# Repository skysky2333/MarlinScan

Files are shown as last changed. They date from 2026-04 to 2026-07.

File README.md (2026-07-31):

# MarlinScan

MarlinScan is a local scanning workstation that uses a Marlin-controlled printer as a motion stage and a USB-tethered Nikon 1 J4 as the image source. It captures overlapping high-resolution tiles from flat or nearly flat subjects and builds a color-consistent mosaic.

The primary application is a Python service with a browser interface. Printer and camera access remain in the local Python process; the browser handles positioning, calibration, scan setup, progress, stopping, and result review.

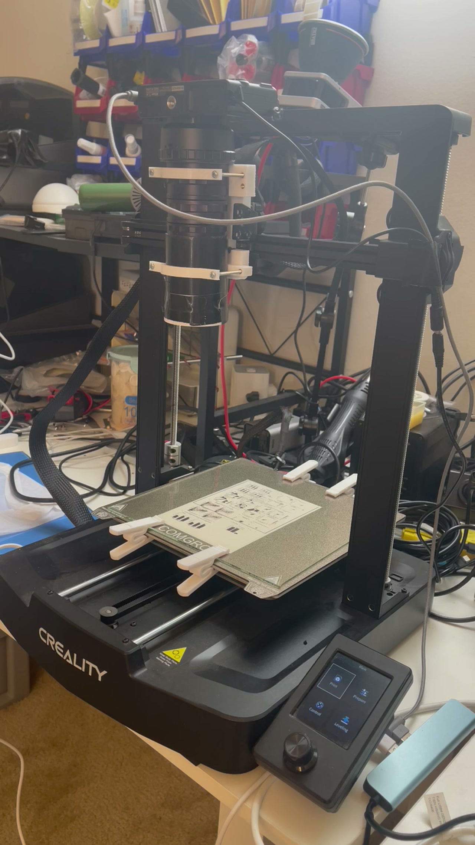
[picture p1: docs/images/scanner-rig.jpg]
MarlinScan hardware scanning a test target


One measured 140-position scan produced a `38,324 x 36,167` image: **1.386 gigapixels at 4,998 DPI**. By output pixel count, that is about 23 times a [61 MP Sony A7R V frame](https://www.sony.com/electronics/support/e-mount-body-ilce-7-series/ilce-7rm5/specifications), 9.2 times a [151 MP Phase One IQ4 frame](https://www.phaseone.com/wp-content/uploads/2021/12/IQ_Camera_System_Overview_Flyer.pdf), and 5.8 times the A7R V's 240.8 MP Pixel Shift output. This is a spatial-output comparison, not a claim of single-shot equivalence: the MarlinScan result required a static flat subject, 140 Nikon captures, stitching, about 53 minutes, and a 67 GB working project. Dynamic range, noise, color accuracy, optical resolution, and motion tolerance still depend on each tile and the physical setup.

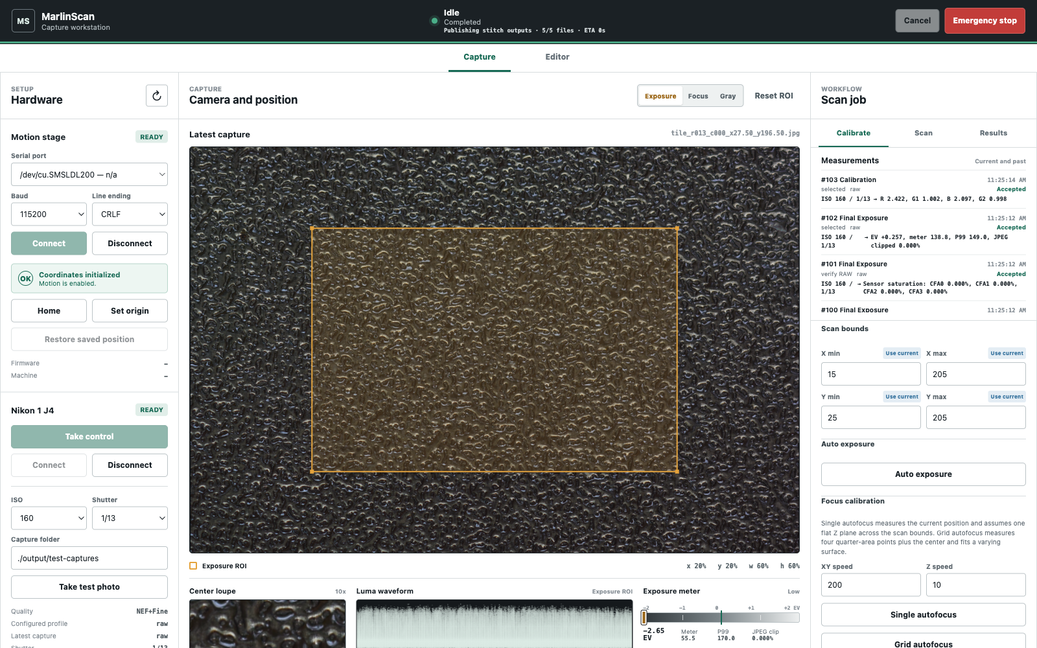
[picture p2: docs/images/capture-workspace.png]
MarlinScan Capture workspace


Start with the [documentation index](docs/index.md), [five-minute workflow](docs/quick-start.md), or [complete configuration reference](docs/configuration.md). The focused guides cover [hardware](docs/hardware.md), [macOS installation](docs/install-macos.md), [Capture](docs/capture-workspace.md), [Editor](docs/editor.md), [outputs and large-image tools](docs/outputs.md), [recovery](docs/troubleshooting.md), [architecture](docs/architecture.md), and the [measured benchmark](docs/benchmarks.md).

## Hardware Scope

- A Marlin-compatible printer or motion stage connected over USB serial
- A Nikon 1 J4 connected directly over Micro-USB and controlled through libgphoto2
- A manual lens and fixed illumination
- A neutral gray reference for white-balance calibration

The primary workflow is USB-only. Nikon Wi-Fi is not used. The J4 does not provide live view over its libgphoto2 USB driver, so the browser displays the latest captured JPEG rather than a video stream.

Set aperture and the lens focus ring physically before calibration. MarlinScan never controls either. Its focus calibration changes the camera-to-subject distance with the printer Z axis.

## Safety And Recovery

- Clear the full configured XYZ travel before connecting or moving the printer.
- Keep the camera mount, lens, nozzle, subject, and cables clear throughout homing, jogging, calibration, and scanning.
- Watch the machine while it moves and keep the emergency-stop control accessible.
- Every new printer connection starts with coordinates uninitialized. Run Home (`G28`), deliberately set the current position as the origin (`G92`), or restore a saved position before motion is enabled.
- MarlinScan remembers the last confirmed XYZ position for each serial port. **Restore saved position** sends that position back with `G92`; it does not move or measure the stage. Use it only when the printer has not physically moved since the position was recorded. Home instead if power loss, released motors, manual handling, or any other event may have changed the position.
- Cancel ends normal work cooperatively after the active command finishes and keeps the printer session and initialized coordinates. Use Emergency Stop when motion must be interrupted immediately.
- Emergency Stop sends `M112` and faults the printer session. Reset or power-cycle the printer if its firmware requires it, disconnect and reconnect it in MarlinScan, then initialize coordinates again.
- MarlinScan cannot change the speed of a `G28` homing cycle. Homing speed is set in the printer's Marlin firmware configuration; the browser speed controls apply to commanded moves and jogging only.

Partial captures already written to disk remain available after a stopped or failed scan. Do not treat an incomplete output folder as a completed mosaic.

## Install On macOS

Python `3.10+` is recommended. Install the gphoto2 CLI and its libgphoto2 dependency, plus native libvips and OpenEXR support:

```bash
brew install gphoto2 vips openexr
```

Install the Python dependencies into the `3dprinter` Conda environment from the repository root:

```bash
conda activate 3dprinter
python -m pip install -r requirements.txt
```

The requirements include the Python gphoto2 binding, FastAPI service, RAW developer, image analysis, serial control, and stitching dependencies.

## Launch

From the repository root:

```bash
conda activate 3dprinter
python -m v3se_printer
```

This starts the service on `http://127.0.0.1:8000/` and opens the default browser. It binds only to this Mac. To suppress browser opening or select another local port:

```bash
python -m v3se_printer --no-open
python -m v3se_printer --port 8010
```

The browser defaults test captures, calibration runs, and scans to `./output/` beneath the directory where MarlinScan was launched. You can replace any of those paths before starting an operation.

Without activating Conda first:

```bash
conda run -n 3dprinter python -m v3se_printer
```

## Nikon USB Session

1. Turn on the Nikon J4 and connect it directly to the Mac with a data-capable Micro-USB cable.
2. Close macOS Photos, Image Capture, and any other camera client.
3. In the Nikon panel, select **Take control**. On macOS this terminates `ptpcamerad`, which otherwise owns the camera interface.
4. Select **Connect**. MarlinScan then keeps one persistent gphoto session for capture and configuration.
5. Select the global ISO and shutter from the values reported by the camera, then take a test capture before moving into calibration. Connection sets the initial shutter to `1/6`.

Taking control can interrupt other macOS photo-import applications. Disconnect the Nikon in MarlinScan before using those applications again.

## Positioning And Capture Feedback

Manual moves default to `200 mm/s` on XY and `10 mm/s` on Z. Hold-to-jog defaults to `100 mm/s` on XY and `10 mm/s` on Z. Calibration and scan motion also default to `200 mm/s` on XY and `10 mm/s` on Z. Adjust these values for the mechanics and payload of the specific stage.

Home first runs the printer's normal `G28`, then raises to `Z203` and moves to the bed center at `X110 Y110`. Confirm that this entire path is clear before starting it.

When the Nikon is connected, MarlinScan automatically captures a **Small / JPEG Basic** still after Home, Restore saved position, each completed manual move, and the end of each jog. These preview captures keep the displayed frame current while minimizing transfer time; they are not scan-quality files. The camera's prior capture settings are restored after each preview.

The latest JPEG view includes three draggable regions for exposure, focus, and the gray reference. The inspection tools show a luma waveform, a robust midtone meter, P99 and JPEG-clipping diagnostics for the exposure region, and a `10x` center loupe for checking detail. These are still-image tools because the J4 USB driver does not provide live view.

## Calibration And Scan

1. Connect the printer, then home it, deliberately set the current position as the origin, or safely restore its remembered position.
2. Connect the Nikon and select the global ISO and shutter used by every capture action.
3. Define the rectangular coverage of the finished image and select separate exposure, focus, and gray-card image regions.
4. Use **Single autofocus** at the current position for a flat subject, or **Grid autofocus** when focus height varies across the coverage.
5. Calibrate exposure, autofocus, and gray-card white balance as separate actions, or use **Run all calibration** to perform the combined workflow. Single autofocus applies its measured Z across the coverage; Grid autofocus measures the four quarter-area centers plus the exact center and fits a focus surface from all five peaks.
6. Confirm the measured camera footprint, which defaults to `25 x 17 mm`, and the desired overlap.
7. Start the scan after exposure, a valid flat or grid focus surface, and white balance are all calibrated. Until then, scanning remains disabled.

The ISO and shutter controls in the Nikon panel are the single source of truth for test captures, calibration, and scans. A scan snapshots their live camera values into `scan_params.json`. Auto exposure changes only the global shutter. It first meters a 2-98 percent winsorized JPEG luminance mean toward `128` as a fast coarse seed, then measures the matching NEF and lengthens an underfilled exposure toward 85 percent P99 in the brightest CFA channel. JPEG clipping, RAW P99, RAW saturation, and black pixels remain diagnostics rather than pass/fail requirements because high-contrast scenes cannot always retain both endpoints. If at least one percent of a RAW channel reaches 99.5 percent of sensor white, MarlinScan shortens the shutter by exactly one available step, verifies again, then accepts the best result with a warning if saturation remains. It never changes ISO or selects a shutter longer than one second.

Each focus-grid point probes `1 mm` below and above its starting Z. A clear improvement extends in that direction; an ambiguous response expands in both directions. The fine pass samples at `0.25 mm` and extends past an edge maximum until the global peak is bracketed. Peak confidence is measured against the complete sweep endpoints, so a broad peak or two-point plateau is valid while a genuinely flat curve fails. There is no user-defined focus range; the configured machine Z limits are the safety boundaries. Single autofocus captures a final analysis frame at the selected peak so the displayed image matches the stage position. The browser logs every focus score and each expansion, bracket, prominence, and selection decision.

Grid autofocus samples the four points formed by the 25 and 75 percent positions across the finished-image coverage area's width and height, plus the exact center. One bilinear surface is fitted from all five measured peaks and used only inside the declared coverage. Single autofocus creates a constant-Z surface from its measured point. After either autofocus mode or Run all calibration, bed clicks, absolute XY moves, XY jogging, and scan tiles automatically use the active surface Z. Z-only moves remain available for deliberate adjustment.

Scan bounds describe the finished image's physical coverage, not the camera-center travel. Defaults are `X15-205 mm` and `Y25-205 mm`; each scan minimum or maximum has a **Use current** button for the corresponding live stage coordinate. The outer tile centers are inset from those bounds by half the `25 x 17 mm` camera footprint, so the outer image edges meet the requested coverage. Tile spacing follows the selected overlap.

Each tile waits `1000 ms` after the final XYZ move before capture by default so stage vibration can decay. The Settle control applies to both normal and Quick acquisition and remains adjustable from `0` to `5000 ms`.

The Position map previews the separated tile grid from the current scan settings before capture. While scanning it shows the serpentine planned route, completed route, current location, completed count, active phase, and estimated phase time remaining. Status refreshes more frequently while work is active, and successful calibration or scanning opens Results automatically without an acknowledgement step.

Normal acquisition downloads each JPEG first so it can appear promptly, then its matching NEF, while RAW development overlaps the following tile. Optional **Quick acquisition** stores every JPEG+NEF pair on the camera card during stage motion, records the remote-to-tile mapping, and imports all pairs before development and stitching. Quick acquisition shortens the moving phase but tile images do not appear until import; normal acquisition remains the default.

Quick acquisition deletes every JPEG+NEF pair owned by that job and restores the previous camera storage target after success, Stop, or failure. It never enumerates or deletes unrelated card files. A deletion or storage-restore failure remains visible as a failed job so camera-space leaks are not hidden.

White balance comes from the selected neutral gray-card region in one matching JPEG+NEF capture. The reference must retain usable, unsaturated samples in every CFA channel. That pair also establishes one global linear exposure multiplier and records the camera-to-Rec.2020 matrix. All three are reused for every tile; per-tile auto white balance and automatic brightness are not used. The recipe also pins the rawpy and LibRaw versions, and regeneration fails if the installed engine differs. RAW development leaves saturated highlights unreconstructed and performs the working-space conversion in float, so unclipped channels and signed out-of-gamut values remain in the scene-linear master instead of being forced to a 16-bit boundary.

The browser estimates the scan sampling density below Camera footprint from the latest Large analysis or RAW capture. It shows X, Y, and nominal DPI and retains that estimate when a Small preview is captured.

The Measurements panel keeps the current session's exposure readings, focus scores, selected peaks, and white-balance gains, including the capture profile used for each measurement.

## Image Roles And Outputs

Each captured tile has four matching files:

- `.nef`: untouched Nikon RAW archival source
- `.jpg`: fine JPEG used for exposure and focus analysis, alignment, and quick inspection
- `_scene_linear.tif`: internal float32 linear Rec.2020 working tile
- `.tif`: deterministic 16-bit sRGB development of the same linear tile for inspection

MarlinScan uses three named Nikon profiles: `preview` is Small / JPEG Basic, `analysis` is Large / JPEG Fine, and `raw` is Large / NEF+Fine. The J4 does not advertise a remotely configurable color-space setting, so profiles contain only camera-supported controls. The Nikon panel shows both the configured profile and the profile that produced the latest image.

A scan directory also contains `scan_params.json`, `raw_development.json`, the incrementally written local `captures.json` and developed `tiles.json` manifests, a losslessly compressed tiled float32 `mosaic_scene_linear.exr`, a flat 16-bit `mosaic_full.tif`, a tiled multi-resolution 16-bit `mosaic_pyramidal.ome.tif`, an 8-bit `mosaic_thumb_2000.jpg`, and exact alignment transforms in `stitch_meta.json`. JPEGs establish alignment once; the same geometry composites the linear tiles, and both display TIFFs are derived from that shared mosaic. The pyramidal OME-TIFF has the same full-resolution pixels and sRGB profile as the flat TIFF, plus reduced-resolution SubIFD levels and OME metadata for whole-slide viewers such as QuPath. Quick acquisition additionally writes `camera_captures.json` as each pair is stored on the camera.

The NEFs, manifests, calibration state, development recipe, and transforms are the canonical editable project. The OpenEXR mosaic is a demosaiced scene-linear derivative that preserves wide-gamut float values above display white for large-scale editing. The TIFF tiles and mosaics remain display-referred sRGB images: demosaicing, calibrated white balance, sRGB conversion, gamma, and channel clipping are baked into them. ISO is fixed when the sensor is exposed and cannot be changed afterward; retain the untouched NEFs when original sensor data or a different development recipe matters.

## Image Editor

The **Editor** workspace loads completed RAW scan projects independently of the capture controls. The full-image view loads the saved 2000-pixel mosaic once; the Local RAW view uses the clickable tile map to load one RAW-derived tile. Both remain in GPU memory, so sliders, the five-point curve, and the eight-band HSL mixer update continuously without a Preview button. Switching back to Full Image does not rebuild the mosaic.

Basic includes a drawn-region global white-balance picker. Film separates Positive/Slide, Color Negative, and B&W Negative development, including unexposed-base sampling, density inversion and range controls, and channel-response controls where applicable. These sampling rectangles set global recipe values; they are not retained local masks. The editor intentionally has no brushes, adjustment masks, selections, dodge, or burn tools.

Custom scan output locations are remembered by the service, so their completed projects remain available in Editor after a restart.

Interactive previews are fast display proxies. **Apply to all RAW** performs the authoritative full-precision operation: it develops every original NEF with the shared recipe, reuses the scan's saved alignment transforms, and writes a new immutable numbered revision beneath the scan folder. Its dedicated progress panel reports every NEF, compositing, EXR, TIFF, pyramid, preview, metadata, and cleanup phase with count and ETA. Each revision contains a linear Rec.2020 working EXR, flat and pyramidal 16-bit TIFFs, a JPEG preview, and the exact edit and revision metadata. Original NEFs and earlier revisions are never overwritten.

Gigapixel scans are normally edited through the full-image proxy or a local RAW tile, then rendered tile by tile and composed with the saved geometry. This is also how large aerial and whole-slide systems avoid loading a complete image into interactive memory. The full-resolution NEF-backed project and float EXR are the archival/editable path; DNG is not the canonical output because common RAW editors cannot reliably open BigDNG mosaics of this size.

## Legacy Desktop And UVC Tools

The earlier Tk desktop application remains available explicitly:

```bash
python -m v3se_printer.app
```

It retains the existing UVC preview, printer maintenance, temperature, tuning, EEPROM, mouse-follow, and older scan tools. Those UVC workflows are separate from the Nikon J4 web workflow and do not add USB live view to the J4.

The standalone UVC browser server is also separate:

```bash
python -m camera_server
```

Only one process can own most UVC cameras at a time. On macOS, grant the terminal or Python launcher camera permission when using UVC hardware.

## Helper Tools

Rebuild outputs from an existing compatible scan folder:

```bash
python tools/restitch_scan.py output/scans/scan_YYYYMMDD_HHMMSS
```

Benchmark realtime serial motion:

```bash
python tools/rt_bench.py --port /dev/cu.wchusbserial1120 --dx 0.5 --feed 6000 --count 80
```

## Repository Layout

- `v3se_printer/web/`: local browser service and interface
- `v3se_printer/service.py`: scan workflow orchestration
- `v3se_printer/nikon.py`: Nikon J4/libgphoto2 camera control
- `v3se_printer/printer.py`: bounded Marlin motion control
- `v3se_printer/calibration.py`: exposure and printer-Z focus calibration
- `v3se_printer/raw.py`: fixed-white-balance 16-bit RAW development
- `v3se_printer/scan/`: tile alignment, composition, and output writing
- `v3se_printer/app.py` and `v3se_printer/ui/`: legacy Tk/UVC application
- `camera_server/`: standalone legacy UVC browser server

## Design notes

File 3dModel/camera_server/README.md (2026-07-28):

# Camera server optical stand

These models support the standalone server launched with `python -m camera_server`. They are separate from the printer-controlled scan mount in `3dModel/printer_scan/`.

- `optical_stand.step`: a 54 mm tube clamp on a wide freestanding rear mount.
- `monolithic_stand_body.step`: an optional version that fuses the stand base, mast, and fixed clamp carrier into one solid.

Printable items 02-04 form the modular stand. Items 05-06 are the monolithic alternative.

The phrase "should be exceed 350 mm" is interpreted as "must not exceed 350 mm in any axis."

## Freestanding optical mount

The clamp is attached radially from behind through the gap between its lower and upper bands. No mast, beam, socket, or floor rail crosses the vertical 54 mm tube path above or below the clamps.

- Overall size: 300 x 288.959 x 288 mm
- Tube bore: 54 mm
- Clamp outside diameter: 62 mm
- Clamp screw axes: 72 mm apart
- Lower clamp: 8 mm high
- Upper clamp: 25 mm high
- Vertical spacing between clamp bases: 65 mm
- Floor rails: 24 mm wide x 16 mm high
- Head beam: 44 mm wide x 50 mm high

The floor base is one continuous print with no leg joints or leg holes. Each front rail first runs sideways to `X=+/-138`, then turns toward the user to `Y=-120`; the rounded rear rails spread to `X=+/-115`, `Y=145`. The forward rails have inner faces at `X=+/-126`, leaving a verified 246 x 155 mm clear floor area from `X=-123..123`, `Y=-105..50` beneath the tube.

The fixed clamp carrier, broad rear beam, mast contact pad, and socket are one solid. Part 4 now presses downward over the rectangular mast through a closed four-sided socket with a 6 mm rear wall, then seats against an integrated top stop. Its 50.6 x 30.6 mm cavity provides 0.30 mm broad-face clearance around the 50 x 30 mm mast. Four rounded side pads create 0.10 mm interference per side, while four front and four rear bearing pads keep the mast aligned without full-face rubbing. A 1 mm chamfer around the mast top provides a gradual lead-in. There is no separate rear bracket, thin center bridge, or head-joint M5 hardware.

## One-piece stand variant

`printable/05_monolithic_stand_body.stl` combines printable items 2, 3, and the fixed carrier from item 4 into one continuous solid. The mast socket is filled and fused through the base, the carrier is fused across the full mast contact face, and the three obsolete M5 assembly holes are removed.

The lower and upper clamp caps remain removable and are supplied together in `printable/06_monolithic_clamp_caps.stl`. They cannot be fused to the body because the 54 mm camera tube must enter through the open front of the clamps.

- Overall body size: 300 x 288.999 x 288 mm
- Body count: one closed solid
- Tube bore and clamp geometry: unchanged from the modular stand
- M5 stand hardware: not required
- Required printer space: 300 x 289 x 288 mm for the body alone, or about 320 x 310 mm with the recommended brim; a 350 x 350 x 350 mm printer is recommended

Print the body upright in its supplied orientation with a 10 mm brim. Use build-plate-only organic support under the fixed carrier, carefully blocked from the tube bore, screw holes, and insert pockets. Use 6-8 walls and 35-45% gyroid or cubic infill for PETG.

The one-piece version removes joints, but its upright mast is built across horizontal layer interfaces. The modular version's horizontally printed mast is directionally stronger and remains the preferred version for a heavy camera or frequent handling.

## Print files

STL does not contain a unit field; these files use millimeter coordinates. Import them as millimeters and keep the supplied orientations.

| File | Quantity | Bounding box | Supports |
| --- | ---: | --- | --- |
| `printable/02_stand_base.stl` | 1 | 300 x 288.999 x 74 mm | None; requires at least 310 x 300 mm usable area; a 350 mm bed leaves brim clearance |
| `printable/03_rear_mast.stl` | 1 | 50 x 250 x 30 mm | None; 5 mm brim recommended |
| `printable/04_optical_head_parts.stl` | 1 | 180 x 128.813 x 80 mm | Build-plate-only organic support under the fixed carrier as needed; 5 mm brim |
| `printable/05_monolithic_stand_body.stl` | 1 | 300 x 288.999 x 288 mm | Build-plate-only organic support under the carrier; 10 mm brim requires about 320 x 310 mm usable area |
| `printable/06_monolithic_clamp_caps.stl` | 1 layout containing 2 caps | 180 x 13.963 x 25 mm | None |

Recommended PETG starting profile for a 0.4 mm nozzle:

- 0.20 mm layers
- 5-6 walls
- 6 top and bottom layers
- 30-40% gyroid or cubic infill
- 5 mm brim on the mast and head layout

Block support from all bolt holes, heat-set insert pockets, the tube bore, and the complete head socket. The supplied head orientation bridges the 30.6 mm socket cavity; use tuned bridge flow and cooling, then remove any loose strings without sanding the broad cavity walls. Dry-fit the base socket and the head press-fit before final assembly. If the head is too tight, lightly sand only the four rounded side pads in equal increments rather than enlarging the full socket.

## Stand hardware

- Base-to-mast retention: 1 x M5x75 bolt, 1 x M5 nyloc nut, and 2 x M5 washers; omit only if the printed socket is securely retained and load-tested
- 6 x M3x45 screws
- 6 x M3 heat-set inserts sized for 4.3 mm diameter, 8 mm deep pockets
- Optional self-adhesive rubber feet

For the one-piece variant, omit all M5 hardware. It requires only the six M3 screws, six heat-set inserts, and optional feet.

## Stand assembly

1. Insert the mast into the base socket. Install the M5x75 retention bolt unless your printed socket has a secure, load-tested friction fit.
2. Align the head above the mast and press it straight downward over the chamfered end until the internal top stop seats firmly on the mast.
3. Install the six M3 heat-set inserts, place the tube between the jaws, and tighten the clamp screws evenly.

For the one-piece variant, skip steps 1-2. Install the inserts, place the tube against the fixed clamp halves, and attach the two removable caps with the six M3 screws.

Load-test the stand over a protected surface before mounting expensive equipment. Add rubber feet, ballast, or bench anchors if the working surface can slide or the camera is unusually heavy.

## Parametric sources

- `optical_stand.py`: monolithic base, chamfered mast, rear-mounted optical clamp, and press-fit head saddle
- `monolithic_stand_body.py`: fused base, mast, and fixed carrier with the joint holes suppressed
- `monolithic_clamp_caps.py`: two-cap print layout for the one-piece stand
- `print_*.py`: build-plate-oriented STEP layouts

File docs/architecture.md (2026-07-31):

# Architecture

## Process Ownership

One local Python service owns the printer serial connection, Nikon gphoto session, calibration state, operation state, manifests, and output publication. The browser is a state-driven client. It does not talk directly to USB devices or infer that an operation succeeded.

Only one scanner operation owns the shared operation lock. Read-only status and result access continue while appropriate; conflicting capture, motion, preview-tile generation, and editor apply requests fail.

## State Model

Important states include connecting, disconnecting, idle, moving, jogging, calibrating, scanning, editing, stopping, and faulted.

Normal Cancel sets a cooperative cancellation event. Every long phase checks it between atomic work units. Emergency Stop bypasses that contract, sends Marlin `M112`, and faults the printer session.

Errors preserve the first cause, publish it through status, and return recoverable camera/calibration failures to Idle. Printer faults remain Faulted until reconnection.

## Capture Pipeline

Normal acquisition follows this flow:

```text
move XYZ -> settle -> capture JPEG+NEF -> download JPEG -> publish latest image
                                      -> download NEF -> develop scene tile
next move/capture overlaps prior host-side RAW development
```

Quick acquisition changes only the acquisition/storage boundary:

```text
move/settle/capture pairs to camera card
  -> import exact recorded JPEG+NEF pairs
  -> delete job-owned remote pairs and restore capture target
  -> develop and stitch locally
```

Every capture is recorded before later processing. Job-owned camera cleanup runs in the operation cleanup path on success, cancellation, and failure.

## Calibration Contract

Exposure, focus, and white balance are global scan inputs. Auto exposure selects one shutter, focus creates either a constant or bilinear Z surface, and gray calibration creates one fixed sensor-channel balance. The matching calibration JPEG+NEF pair also determines one global RAW display exposure multiplier.

Per-tile automatic brightness and white balance are prohibited because they would turn local content differences into mosaic seams.

## RAW And Stitching

Each NEF is demosaiced into scene-linear camera RGB, transformed through the calibrated camera-to-XYZ/Rec.2020 matrix, and retained as float32. A separate display conversion produces the 16-bit sRGB tile.

Fine JPEGs establish alignment geometry. Scene-linear and display mosaics reuse that exact geometry. Float compositing preserves signed values and values above one. Large mosaics use memory mapping and tiled writers rather than requiring all outputs in RAM.

## Output Publication

Writers create artifacts in the active job/revision area and publish only completed files. Metadata declares exact output names and roles. Results endpoints allowlist known artifact keys and bind editor downloads to the last published revision.

The OME-TIFF writer creates a full-resolution tiled base plus reduced SubIFD levels and OME metadata. BigTIFF addressing and pyramid levels are independent properties; the output has both.

## Editor Preview

The browser editor has one Full and one Local WebGL2 texture. JPEG inputs are decoded without browser color conversion, decoded from sRGB to linear, transformed to Rec.2020, processed with recipe v2, transformed back to sRGB, and displayed. Recipe changes are batched with `requestAnimationFrame`. These proxies intentionally trade RAW headroom and exact pre-composite nonlinear behavior for interactive speed; apply remains the authoritative float32 render.

Temporary white-balance and film-base rectangles read the decoded proxy through a float WebGL framebuffer. They produce global recipe estimates and then disappear.

The server tile endpoint returns only a neutral RAW-derived local tile. There is no full-mosaic edit-preview POST. This prevents interactive edits from acquiring the operation lock and recompositing every tile.

## Editor Apply

An apply operation reads original NEFs, not the JPEG proxy or prior TIFF. It writes a new `revision-NNN` directory, uses saved alignment, and regenerates all authoritative derivatives. Failure or cancellation removes the unpublished partial revision.

Recipe v2 is strict and records material mode, Basic controls, RGB balance, film parameters, master curve, and eight-band HSL arrays. The Python and WebGL implementations share operation order and validated ranges.

## Module Map

| Module | Responsibility |
| --- | --- |
| `v3se_printer/service.py` | ownership, state, orchestration, cancellation, progress |
| `v3se_printer/nikon.py` | J4 configuration, capture, download, remote cleanup |
| `v3se_printer/printer.py` | bounded serial motion and remembered position |
| `v3se_printer/calibration.py` | exposure, focus sweeps/surfaces, white balance |
| `v3se_printer/raw.py` | pinned deterministic scene-linear development |
| `v3se_printer/editor.py` | projects, recipe v2, revisions |
| `v3se_printer/scan/` | alignment, composition, EXR/TIFF/preview writers |
| `v3se_printer/web/server.py` | strict HTTP/WebSocket boundary |
| `v3se_printer/web/static/` | Capture UI and GPU editor |

## Product Requirements

[PRD.md](../PRD.md) is the authoritative high-level product contract. It deliberately excludes endpoint and function implementation details.

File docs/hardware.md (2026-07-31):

# Hardware And Physical Setup

MarlinScan assumes a rigid, downward-looking camera over a flat subject on a Marlin-controlled XY/Z platform. Software calibration cannot correct a moving mount, changing illumination, or a subject that shifts between tiles.

## Required Components

- Marlin-compatible printer or motion stage with known XYZ bounds
- Nikon 1 J4 and data-capable Micro-USB cable
- rigid camera and lens mount
- manual lens with physical aperture and focus controls
- fixed, flicker-free illumination
- neutral gray reference photographed under the scan light
- subject retention that does not enter the optical area
- sufficient local storage for NEFs, working tiles, mosaics, and revisions

Physical MarlinScan rig

## Camera Geometry

Mount the sensor plane as parallel to the subject plane as practical. Grid autofocus can compensate for a moderate height slope, but it does not correct perspective, lens tilt, or a subject that moves.

Measure the physical width and height visible in a Large Nikon frame at the chosen working distance. Enter those values as Camera footprint. The current rig uses 25 x 17 mm. Changing lens, focus, extension, camera height, or sensor crop invalidates that measurement and the DPI estimate.

Set aperture physically before exposure and focus calibration. Smaller apertures increase depth of field but eventually lose detail to diffraction and may require longer exposures. Choose the aperture from actual resolved-detail tests, not f-number alone.

## Rigidity And Stabilization

The camera mass and macro extension act as a long lever. Check:

- no play in the carriage or camera plate;
- no rotation at lens adapters or extension tubes;
- cables have a service loop and do not pull differently across the bed;
- belts, wheels, rails, and Z screw are adjusted consistently;
- the subject is clamped outside the scanned rectangle;
- the nozzle or unused toolhead cannot strike the subject or mount.

Use the 1000 ms settle default as a starting point. If Local RAW tiles show movement blur, increase settle and reduce acceleration or speed before changing image-processing controls.

## Illumination

Keep light output, spectrum, angle, and room spill fixed from calibration through the final capture. Avoid PWM sources whose output varies during the shutter interval. Diffusion should be stable and mechanically separate from moving parts where possible.

For transmissive negatives, use an even backlight and control reflections from the lens side. Include clear unexposed film for base sampling. For reflective originals, place the gray reference in the same light and orientation as the subject.

## Cable And Travel Safety

Before Home or any scan, move the unpowered or safely jogged mechanism through the full intended envelope and inspect cable slack at every corner. The post-home move includes Z203 and X110/Y110. Keep the Nikon USB connector, camera body, lens, mount, clamps, subject, and lighting clear of the complete path.

Keep access to printer power and the MarlinScan Emergency stop. Cancel is not an immediate motion interrupt.

## Storage

The measured 140-position scan occupied 67 GB before editor revisions. Ensure the working volume has room for source files, a full float mosaic, two large TIFFs, and temporary compositing data at the same time. Prefer fast internal SSD storage. Do not scan directly to a network share whose latency or disconnection can interrupt atomic file publication.

## Validation Before A Large Job

1. Capture one Large JPEG+NEF at the intended ISO, shutter, aperture, and illumination.
2. Verify focus in the center and corners of the physical coverage.
3. Run Single or Grid autofocus and inspect every reported peak.
4. Scan a 2 x 2 or 3 x 3 representative area.
5. Inspect Local RAW tiles for vibration and the mosaic for alignment or exposure seams.
6. Confirm the output folder and free space.
7. Only then start the full path.

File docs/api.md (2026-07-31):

# HTTP API

The local FastAPI service exposes interactive documentation at `/docs` and its schema at `/openapi.json`. It binds to `127.0.0.1` in the packaged launcher and has no authentication boundary for network deployment.

## Principles

- JSON request models are strict and reject unknown fields.
- Numeric trust boundaries require finite values and enforce physical/control ranges.
- Hardware/state conflicts return HTTP 409.
- invalid requests and recipes return HTTP 422;
- missing files/projects return HTTP 404;
- camera, printer, operating-system, and writer failures return HTTP 503;
- result downloads use allowlisted artifact names rather than client filesystem paths.

## Status

`GET /api/status` is the browser's source of truth. Important fields include:

- `state`, `message`, and `error`;
- `printer` and `camera` status;
- `calibration`, `focus_grid`, and `quick_calibration`;
- `measurements`;
- `scan_progress` geometry;
- one shared `step_progress` object;
- latest scan/editor result descriptors.

Step progress contains a machine step name, user-facing label, completed count, optional total, unit, and optional `eta_seconds`. An omitted total means the phase is adaptive or not yet finite.

## Printer Endpoints

The printer group covers port discovery, connect/disconnect, Home, origin, remembered-position restore, bounded absolute movement, cooperative stop, and emergency stop. Motion requests accept explicit XY and Z speeds within service limits.

Realtime jogging uses `/ws/jog`. Each message contains a normalized direction vector and XY/Z speeds. XY and Z are not combined in one jog vector. The browser renews held motion; release, blur, page hide, or an expired lease stops the command.

## Camera Endpoints

The camera group covers macOS ownership, persistent connection, ISO, global shutter, and test capture. Settings are selected from camera-advertised choices and verified by readback.

## Calibration Endpoints

Separate endpoints start auto exposure, single autofocus, grid autofocus, gray white balance, or the combined calibration plan. Requests contain normalized ROIs, shared physical coverage, folders, and relevant speeds.

Starting an operation returns the current status immediately. The browser polls status for phase updates and completion.

## Scan Endpoint

`POST /api/scan/start` accepts coverage, footprint, overlap, folder, speed, stabilization delay, and Quick acquisition. The server constructs and validates the plan and rejects it unless camera, printer, exposure, focus, and white-balance prerequisites are satisfied.

## Editor Endpoints

| Endpoint | Purpose |
| --- | --- |
| `GET /api/editor/projects` | discover completed RAW scan projects |
| `POST /api/editor/project` | load strict project details, tile labels, normalized aligned bounds, and preview URL |
| `GET /api/editor/original-preview` | return the saved 2000 px mosaic JPEG |
| `GET /api/editor/tile-preview` | return one neutral RAW-derived tile JPEG by project and index |
| `POST /api/editor/apply` | start a full recipe-v2 revision |
| `GET /api/editor/results/{artifact}` | download an allowlisted last-revision artifact |

There is intentionally no full edited-preview endpoint. Interactive processing occurs in the browser; full precision occurs in apply.

## File Results

Scan and editor result endpoints expose declared artifacts only. A query path cannot redirect them to an arbitrary local file. Original per-tile files remain inside the scan directory and are not individually exposed as unrestricted download paths by this API.

## Hardware Automation Warning

The API being local and documented does not make unattended physical motion safe. Client code must still respect visible state, machine clearance, camera ownership, and human supervision. Do not issue Home, move, scan, remote deletion, or Emergency Stop as a documentation or health-check request.

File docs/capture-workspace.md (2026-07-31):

# Capture Workspace

The Capture workspace is organized into Hardware, Camera and position, and Scan job. All controls reflect service state; a disabled command is unavailable because a prerequisite is missing or another operation owns the scanner.

## Top Status

The header always shows:

- service state, such as Idle, Moving, Calibrating, Scanning, Editing, or Faulted;
- the current phase message;
- completed and total units when the phase is finite;
- an ETA derived from measurements in that phase;
- cooperative **Cancel** and hardware **Emergency stop**.

An expanding autofocus sweep has no known final sample count, so it reports completed samples and `ETA unavailable` until the search converges. It does not invent a total.

## Motion Stage

Select a serial port and connect. Coordinates remain uninitialized until Home, Set origin, or safe remembered-position restore succeeds. Motion controls remain disabled before initialization.

Home runs the printer's firmware-defined `G28`, raises to Z203, and moves to X110/Y110. Browser speed controls cannot change firmware homing speed.

Restore saved position sends `G92` with the last confirmed XYZ for the same serial port. It performs no physical measurement or movement. Do not use it after power loss, released steppers, manual movement, or any uncertain position continuity.

## Nikon Panel

**Take control** releases the macOS PTP camera process. **Connect** opens the persistent gphoto session. ISO and shutter are global values used by test capture, calibration, focus, white balance, and scanning.

MarlinScan uses three capture profiles:

| Profile | Nikon quality | Use |
| --- | --- | --- |
| Preview | Small / JPEG Basic | Automatic stills after motion |
| Analysis | Large / JPEG Fine | Test, exposure, focus, and gray reference |
| RAW | Large / NEF+Fine | Calibration verification and scan tiles |

The panel shows both the configured profile and the profile that produced the displayed still.

## Latest Capture And ROIs

Exposure, Focus, and Gray are independent normalized rectangles. Select a mode, then drag its region over the image. Reset ROI restores the selected region to the center 60 percent.

- Exposure should represent the tones whose midrange should drive shutter selection. Small specular highlights can remain outside or inside the region; they do not become a hard failure.
- Focus should contain fine, high-contrast, non-repeating detail at the intended subject plane.
- Gray should contain a neutral reference with usable, unsaturated samples in every sensor channel.

## Inspection Tools

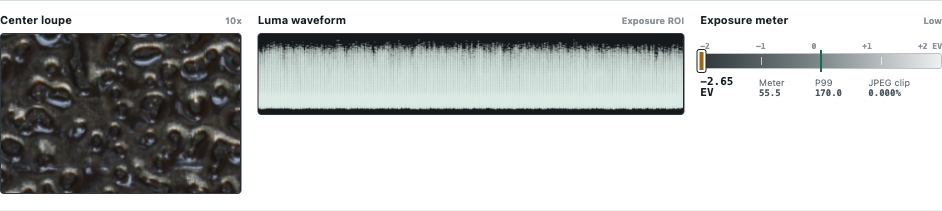
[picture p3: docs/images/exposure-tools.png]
Loupe, waveform, and exposure meter


The 10x center loupe checks local detail in the latest still. The waveform shows luma distribution in the Exposure ROI. The meter uses robust middle tones; P99 and JPEG clipping remain diagnostics.

Auto exposure changes shutter only. It first finds a coarse JPEG exposure, then checks a matching NEF and moves the brightest CFA-channel P99 toward 85 percent of the black-to-white sensor range. That target is an optimization, not an acceptance gate. High-contrast scenes may legitimately contain both saturated highlights and black shadows. Meaningful sensor saturation can shorten shutter by one available step; any remaining endpoint loss is reported rather than hiding the completed exposure.

## Position And Focus Surface

The bed map accepts a click target and shows current position, target, scan footprints, route, and focus information. With a focus surface active, changing X/Y computes Z from that surface. Z-only jog remains deliberate manual control.

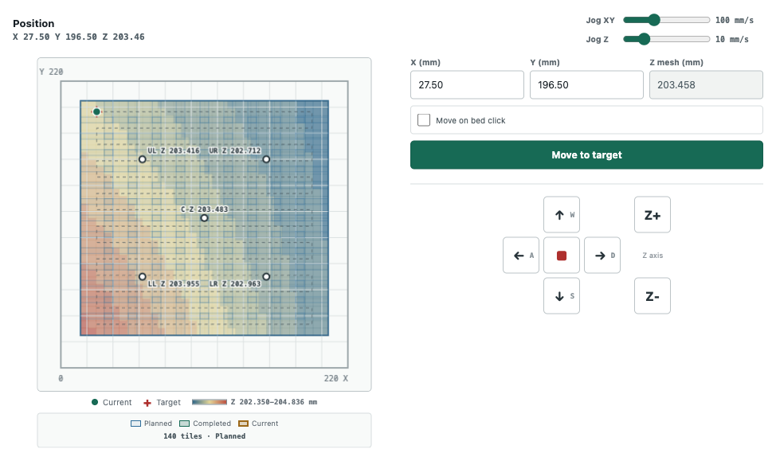
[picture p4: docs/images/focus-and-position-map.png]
Position and measured focus surface


Single autofocus creates one constant-Z surface from the current point. Grid autofocus measures lower-left, upper-left, center, lower-right, and upper-right positions and fits one bilinear surface. The center is both part of the fit and shown independently on the map.

## Measurements

The right-side log keeps current-session exposure readings, focus samples and selected peaks, and white-balance gains. Each entry records phase, capture profile, parameter, result, time, and whether it was accepted. This is evidence for diagnosing a calibration instead of a generic pass/fail light.

## Calibration Tab

The shared bounds define finished-image physical coverage. Standalone actions update one calibration component:

- Auto exposure
- Single autofocus
- Grid autofocus
- Calibrate gray white balance

**Run all calibration** performs preliminary exposure, five-point grid focus, final RAW-aware exposure, and gray white balance. Scan becomes available after exposure, either valid focus model, and white balance exist.

## Scan Tab

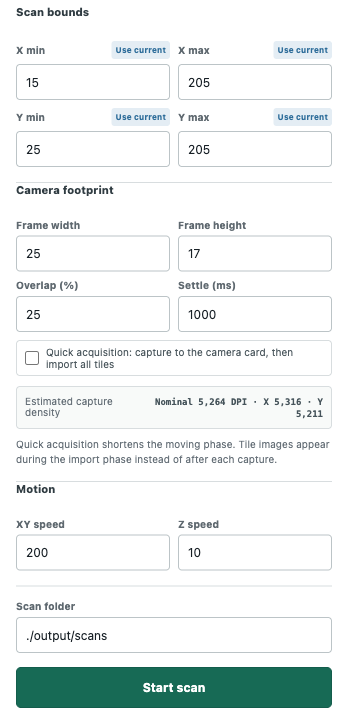
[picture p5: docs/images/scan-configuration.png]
Scan configuration


Camera footprint describes one tile's physical coverage. Overlap and bounds determine tile count and redistributed spacing. The displayed DPI is an estimate from the latest Large analysis/RAW dimensions and footprint; final stitch metadata is authoritative.

Settle is the delay after the final XYZ movement and before capture. It defaults to 1000 ms because the camera and macro mount require time to stop vibrating. Increase it if fine detail shows directionally consistent blur; measure again rather than compensating with sharpening.

Normal acquisition downloads the fine JPEG first, displays it, downloads the matching NEF, and overlaps RAW development with later captures. Quick acquisition stores exact JPEG+NEF pairs on the camera card during motion, imports them afterward, and then develops and stitches. Quick owns only paths returned for that job and deletes those remote pairs on success, cancellation, or failure.

## Results Tab

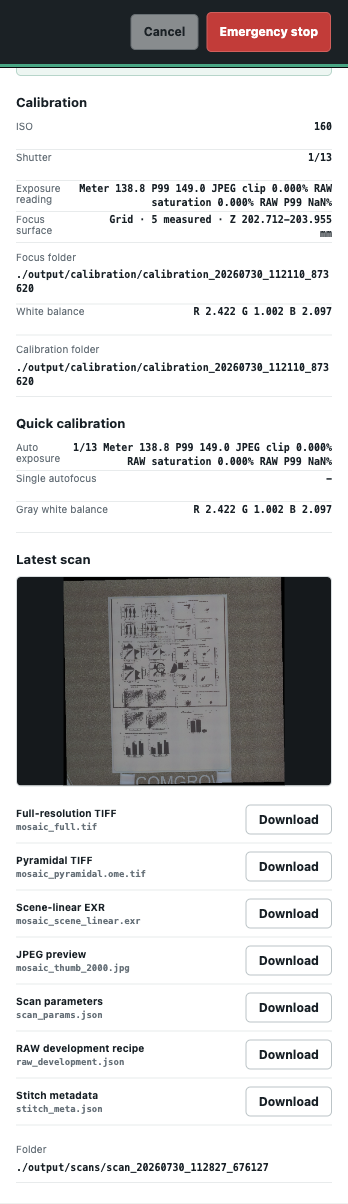
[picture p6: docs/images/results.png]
Results and output links


Results shows calibration, quick standalone calibration values, the latest stitched preview, downloads, and output folders. A link exists only when the corresponding file exists. See [Outputs](outputs.md) before deciding which artifact is the archival master.

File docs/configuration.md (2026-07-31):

# Configuration Reference

MarlinScan currently has no broad application configuration file. Runtime hardware choices and job parameters are explicit in the browser, while the local bind address and port are launch options. Operation manifests record the values used for each calibration and scan.

## Launch

| Setting | Default | Valid values |
| --- | --- | --- |
| Bind address | `127.0.0.1` | Localhost only in the packaged launcher |
| Port | `8000` | `1-65535` |
| Open browser | yes, after 0.8 s | `--no-open` disables it |

```bash
python -m v3se_printer --port 8010 --no-open
```

Run from the intended working directory. Relative output paths resolve from that directory.

## Output Folders

| Operation | Browser default |
| --- | --- |
| Test capture | `./output/test-captures` |
| Calibration | `./output/calibration` |
| Scan | `./output/scans` |

Each operation creates a uniquely named child where required. Scan roots used successfully are recorded so Editor can rediscover completed projects after a service restart.

## Machine Envelope And Position

| Setting | Default or range |
| --- | --- |
| X bounds | `0-220 mm` |
| Y bounds | `0-220 mm` |
| Z bounds | `0-250 mm` |
| Initial browser target | X110, Y110, Z203 |
| Post-home target | X110, Y110, Z203 |
| Absolute XY speed | `200 mm/s` |
| Absolute Z speed | `10 mm/s` |
| Jog XY speed | `100 mm/s` |
| Jog Z speed | `10 mm/s` |
| Maximum XY command speed | `300 mm/s` |
| Maximum Z command speed | `50 mm/s` |

The service enforces bounds and focus-surface Z independent of browser validation. Firmware controls `G28` homing speed.

## Serial

| Setting | Default | Browser choices |
| --- | --- | --- |
| Baud | `115200` | `115200`, `250000`, `230400`, `57600` |
| Line ending | CRLF | CRLF or LF |

The selected port is also the identity used for remembered-position storage.

## Nikon

| Setting | Default |
| --- | --- |
| ISO after connection | `160` |
| Shutter after connection | `1/6 s` |
| Longest auto-exposure shutter | `1 s` |
| Preview profile | Small / JPEG Basic |
| Analysis profile | Large / JPEG Fine |
| RAW profile | Large / NEF+Fine |

ISO and shutter choices are populated from values advertised by the attached camera. Unsupported or global-shutter sentinel values are not offered as valid captures. Aperture and lens focus are physical settings.

## Inspection Regions

Exposure, Focus, and Gray each default to the center 60 percent:

```json
{"x": 0.2, "y": 0.2, "width": 0.6, "height": 0.6}
```

Coordinates are normalized to image width and height. Each region must remain fully inside the image.

## Coverage And Scan Planning

| Setting | Default | Range |
| --- | ---: | ---: |
| X minimum | 15 mm | `0-220` |
| X maximum | 205 mm | `0-220` |
| Y minimum | 25 mm | `0-220` |
| Y maximum | 205 mm | `0-220` |
| Camera frame width | 25 mm | positive |
| Camera frame height | 17 mm | positive |
| Overlap | 25% | `0.1-89.9%` |
| Stabilization | 1000 ms | `0-5000 ms` |
| Scan XY speed | 200 mm/s | `>0-300` |
| Scan Z speed | 10 mm/s | `>0-50` |
| Quick acquisition | off | off/on |
| Route | serpentine | fixed on |

Calibration and Scan fields are synchronized views of one coverage rectangle. Minimum must be less than maximum. The stage center path is inset from finished-image edges by half the camera footprint.

At defaults, MarlinScan plans 10 columns by 14 rows, or 140 tiles. Nominal steps are 18.75 x 12.75 mm; redistributing the outer centers to meet the exact requested edges yields approximately 18.333 x 12.538 mm.

## Autofocus

| Setting | Value |
| --- | ---: |
| Coarse Z step | 1 mm |
| Fine Z step | 0.25 mm |
| Minimum peak prominence | 10% above both sweep endpoints |
| Grid positions | 25%/75% Cartesian points plus exact center |
| Single model | constant Z |
| Grid model | bilinear surface fitted from all five observations |

The search expands until a peak is bracketed or a hard Z limit is reached. A flat sweep fails. A two-sample plateau can be valid and selects its midpoint.

## Exposure

| Setting | Value |
| --- | ---: |
| JPEG coarse target | robust middle-tone value 128 |
| JPEG trim | 2nd-98th percentiles |
| Coarse tolerance | 1/3 EV |
| RAW optimization target | brightest CFA-channel P99 at 85% of black-to-white range |
| Meaningful saturation threshold | at least 1% of a channel at 99.5% sensor white |

JPEG P99, JPEG clipping, RAW P99, RAW saturation, and black occupancy are reported diagnostics. None is a universal acceptance requirement. The selected best exposure can retain clipped highlights or black shadows in a high-contrast scene.

## Output Encoding

| Setting | Value |
| --- | --- |
| Working color space | scene-linear Rec.2020 |
| Editable mosaic | tiled float32 OpenEXR, ZIP compression, 256 px tiles |
| Display mosaic | 16-bit sRGB BigTIFF, Deflate |
| Pyramidal mosaic | 16-bit sRGB OME-TIFF, 256 px tiles, reduced SubIFDs |
| Preview | maximum 2000 px, JPEG quality 88 |
| Alignment | JPEG-derived, saved and reused |
| Blend | weighted feather |
| Per-tile auto brightness/WB | disabled |
| Highlight reconstruction | disabled in the canonical recipe |

## Editor Recipe V2

All values are global and finite. Array lengths are strict.

| Control | Default | Range |
| --- | ---: | ---: |
| Material | `positive` | `positive`, `color_negative`, `bw_negative` |
| Exposure | 0 EV | `-8..8` |
| Temperature, tint, contrast, highlights, shadows | 0 | `-1..1` |
| Black point | 0 | `-1..0.95` |
| White point | 1 | `0.01..8`, greater than black |
| Saturation | 1 | `0..3` |
| RGB balance | 1 each | `0.1..4` |
| Film base RGB | 1 each | `0.01..4` |
| Film density | 1 | `0.1..4` |
| Film Dmin | 0 | `-4..4` |
| Film Dmax | 4 | `-4..8`, greater than Dmin |
| Film red/blue ratios | 1 | `0.1..4` |
| Slide fade repair | 0 | `0..1` |
| Slide black RGB | 0 | finite, each below its white |
| Slide white RGB | 1 | finite, each above its black |
| Master curve | `[0,.25,.5,.75,1]` | five values in `0..1` |
| HSL hue | eight zeros | eight values in `-30..30` degrees |
| HSL saturation/lightness | eight zeros | eight values in `-1..1` |

Editor recipe JSON is strict: version must be `2`, every declared field must be present in the saved recipe, and unknown fields fail validation.

## Persisted Evidence

Important job settings are written into `scan_params.json`, `raw_development.json`, `tiles.json`, and `stitch_meta.json`. Do not edit these files in place. Create a new scan or editor revision so the evidence and output remain consistent.

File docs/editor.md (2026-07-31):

# Image Editor

The Editor is a separate top-level workspace for global, repeatable RAW development. It does not control hardware and intentionally has no brushes, adjustment masks, selections, dodge, or burn. One recipe applies to every tile so adjacent images cannot drift independently.

## Project And Preview Model

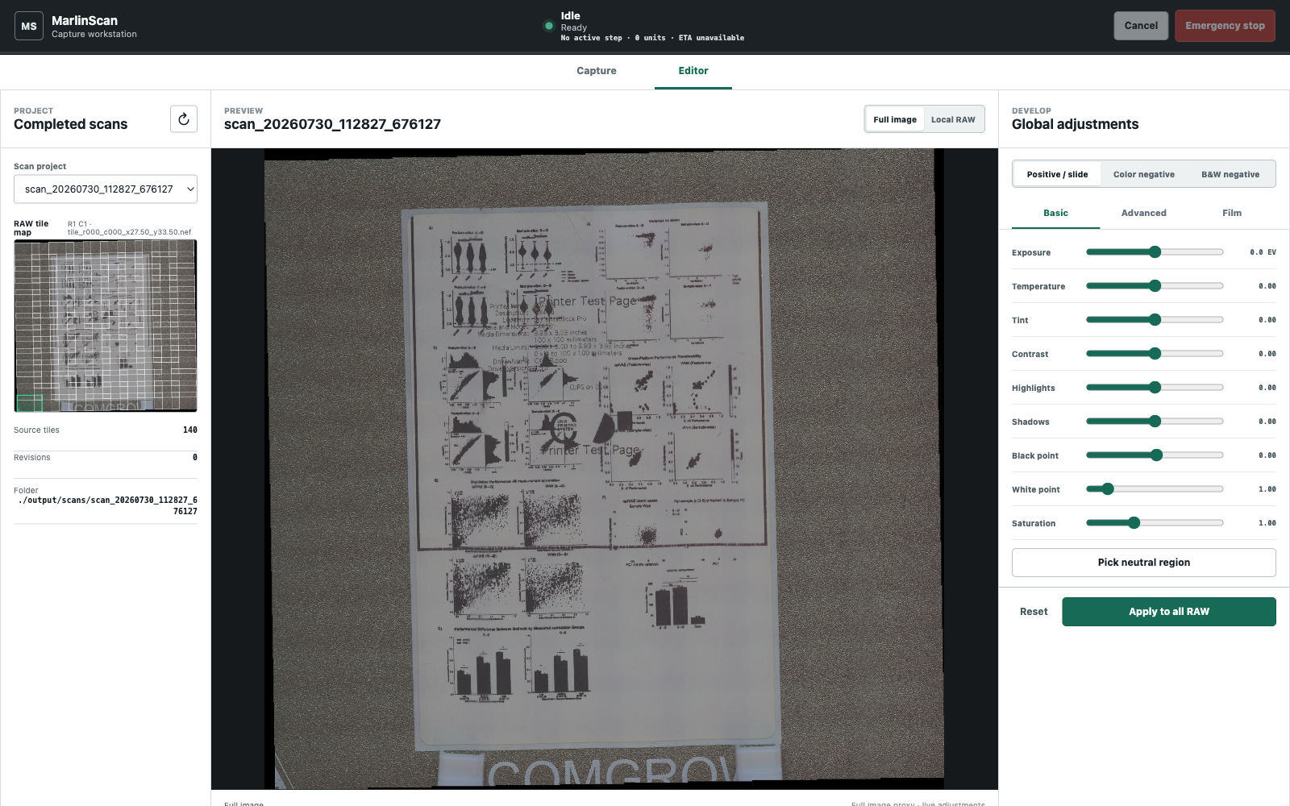
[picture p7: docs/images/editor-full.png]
Full-image editor


Select a completed RAW scan in the left pane. The project list survives service restarts, including custom scan roots previously used by the service.

The Full Image view loads `mosaic_thumb_2000.jpg` once into a GPU texture. Every control update is rendered on the next browser animation frame. The full mosaic is not opened, recomposited, or transferred for each edit.

The RAW tile map overlays actual saved alignment bounds on the stitched thumbnail. Click any rectangle, use the tile list, or use arrow keys on the map to open the corresponding Local RAW view.

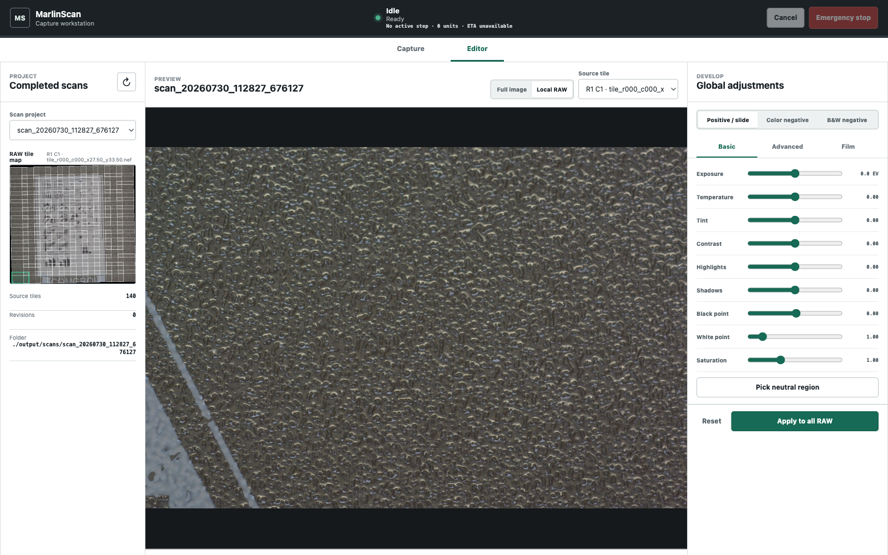
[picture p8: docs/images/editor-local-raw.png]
Local RAW tile selected from the map


Local RAW performs one server request for a neutral JPEG generated from that tile's scene-linear working image. It then uses the same cached GPU recipe. Selecting another tile replaces the local texture. Returning to Full Image switches back to the already loaded texture without a request.

Both views are 8-bit display proxies. They cannot show values above display white, signed wide-gamut values, or every subtle RAW adjustment. Local RAW has more spatial detail but is still a JPEG proxy. Nonlinear preview operations also occur after the thumbnail was feather-composited, while final rendering edits each float tile before composition, so overlap tones can differ slightly. **Apply to all RAW** is the authoritative float32 operation.

## Material Modes

Choose the source material before judging tone and color:

- **Positive / slide** preserves normal polarity and optionally repairs channel-dependent fade.
- **Color negative** converts base-relative transmission to optical density, inverts it, and provides color density ratios.
- **B&W negative** uses the same density model, then produces a neutral luminance result without irrelevant color-ratio controls.

Changing material updates the preview immediately and shows only relevant Film controls.

## Basic

Basic contains exposure, temperature, tint, contrast, highlights, shadows, black point, white point, and saturation.

**Pick neutral region** temporarily enables a rectangle over the active preview. Draw over a neutral subject area. Keyboard users can move the initial rectangle with the arrow keys, resize it with Shift+Arrow, apply with Enter, or cancel with Escape. MarlinScan samples the unedited display proxy and sets the global temperature/tint values. The rectangle disappears after sampling and is not retained as a local correction. For the best estimate, use Local RAW and avoid a region clipped in the proxy; the saved values are then applied to the float RAW tiles.

For negatives, perform light-source white balance before using film-base and print-style controls. A neutral reference photographed under the same light is preferable to guessing from image content.

## Advanced

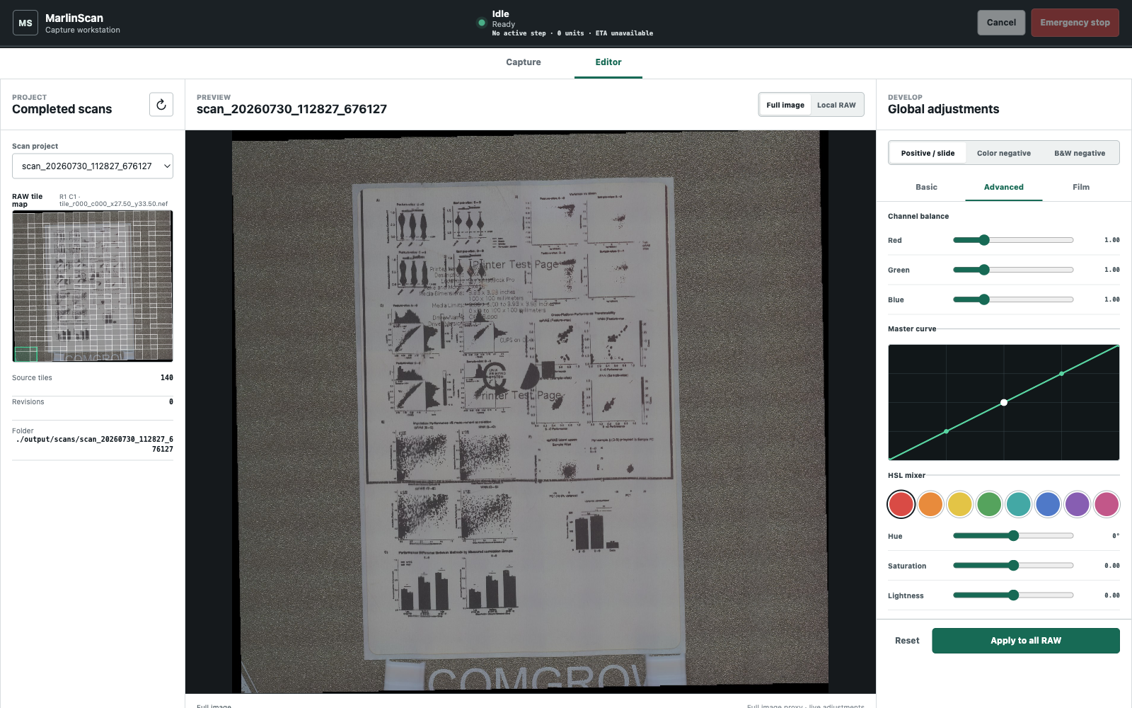
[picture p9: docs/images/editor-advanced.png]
Curve and HSL mixer


Channel balance scales linear Rec.2020 red, green, and blue globally.

The master curve has five fixed input positions from black through white. Drag a point vertically. Keyboard Left/Right selects a point; Up/Down changes it by 0.01. The curve changes luminance while retaining values below zero and above one outside its display range.

The HSL mixer has Red, Orange, Yellow, Green, Aqua, Blue, Purple, and Magenta bands. Select a swatch, then adjust Hue, Saturation, and Lightness. Adjacent bands interpolate smoothly. HSL is useful for global dye and print-color correction; it is not a replacement for a color target and calibrated camera profile.

## Positive / Slide Film Tools

Fade repair blends toward per-channel black/white normalization. Keep it at zero when the positive is already balanced. For a faded slide, set each channel's black and white endpoints from representative clear and dense regions, then increase Fade repair only as far as needed.

Channel endpoints must remain ordered. Apply is blocked when any channel white is not greater than its black.

## Color Negative Film Tools

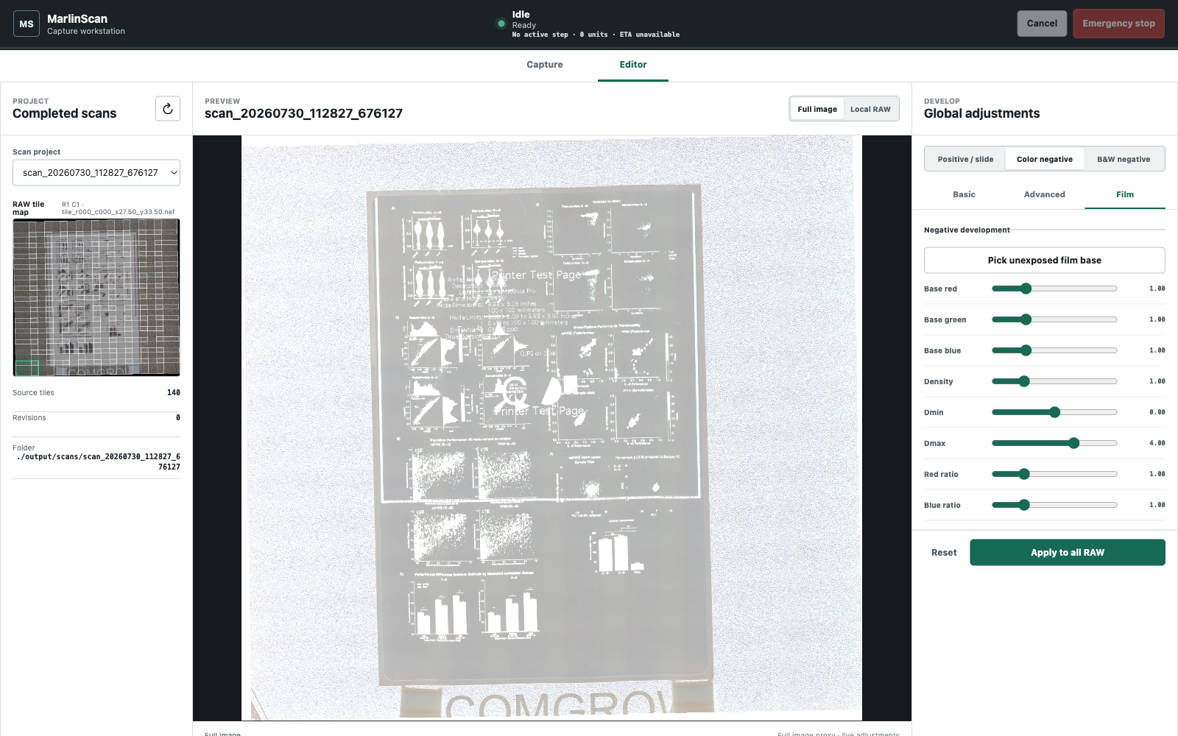
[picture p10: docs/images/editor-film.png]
Color-negative controls


Use **Pick unexposed film base** on a clear piece of the same film outside the exposed frame. MarlinScan estimates the mean linear Rec.2020 red, green, and blue transmission from the unedited display proxy and records it as the global base. Use Local RAW and confirm that the base is not clipped. This neutralizes the orange base before density inversion; it does not create an image mask.

The density operation is base-relative:

```text
density = -log2(max(channel / film_base, epsilon))
```

Density scales the overall response. Dmin and Dmax map the useful density interval to the working tonal interval. Red ratio and Blue ratio correct channel response relative to green. Start with ratios at 1.0 and change them only after selecting a credible film base.

This design follows photographic sensitometry concepts such as film base plus fog, Dmin/Dmax, and characteristic-curve endpoints. It is implemented directly for MarlinScan's scene-linear Rec.2020 pipeline. NegPy is not embedded: its current package requires Python 3.13, exposes no stable headless processing API, and its published wheel omits the processing subpackages.

## B&W Negative Film Tools

Pick the unexposed base and set density range as with color negative. The result is converted to Rec.2020 luminance and replicated to neutral RGB. Red/blue density controls remain hidden because they would imply color information that the output discards.

## Applying A Recipe

Select **Apply to all RAW** when the proxy looks correct and critical areas have been checked in Local RAW. MarlinScan then:

1. validates and writes the versioned recipe;
2. redevelops every original NEF into the recorded scene-linear Rec.2020 space;
3. applies the same material and global edit recipe to every tile;
4. reuses the original JPEG-derived transforms;
5. composites a new float32 mosaic;
6. writes the working EXR, flat TIFF, OME pyramid, JPEG preview, and metadata;
7. removes scratch files and publishes an immutable numbered revision.

The editor progress panel reports the active phase, completed/total units, and ETA. Cancel is cooperative. A cancelled or failed partial revision is removed; original scan files and earlier revisions are untouched.

Revisions live under:

```text
scan_.../revisions/revision-001/
scan_.../revisions/revision-002/
```

Each has its own `edit_recipe.json` and `revision_meta.json` so the output is attributable and reproducible.

## Performance Expectations

On the measured 140-tile, 1.386 GP project in desktop Chrome:

| Interaction | Measured time |
| --- | ---: |
| Initial Full Image proxy | 194-264 ms |
| First Local RAW tile | 890-895 ms |
| Cached Local RAW to Full Image | 25-29 ms |
| Slider input through two rendered frames | 25-27 ms |

Those interactions generated no `/api/editor/preview` requests. Full apply remains intentionally much slower because it reads and develops every NEF and writes gigapixel artifacts.

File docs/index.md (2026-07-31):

# MarlinScan Documentation

MarlinScan turns a Marlin-controlled motion platform and tethered Nikon 1 J4 into a local, calibrated, gigapixel scanning workstation. The browser controls capture and global RAW development; the Python service exclusively owns hardware, files, operation state, and recovery.

## Start Here

1. [Hardware and physical setup](hardware.md)
2. [Install on macOS](install-macos.md)
3. [Five-minute workflow](quick-start.md)
4. [Capture workspace](capture-workspace.md)
5. [Image editor](editor.md)

## Reference

- [Configuration reference](configuration.md): every important default, range, unit, and folder
- [Outputs and large-image workflows](outputs.md): NEF, EXR, TIFF, OME pyramid, QuPath, and archival roles
- [Troubleshooting and recovery](troubleshooting.md): camera ownership, capture errors, cancellation, saved position, Quick cleanup, and incomplete jobs
- [Architecture](architecture.md): process ownership, state machine, capture pipeline, and editor revisions
- [Measured benchmark](benchmarks.md): the 1.386 GP example and honest camera comparisons
- [HTTP API](api.md): endpoint groups, validation, status, progress, and WebSocket jogging

## What The System Produces

The canonical project is not one giant DNG. It is the original NEFs plus calibration, manifests, the pinned RAW-development recipe, and saved alignment transforms. Those sources can regenerate the image without throwing away sensor data.

The full-resolution editable derivative is a tiled float32 scene-linear Rec.2020 OpenEXR. Delivery and inspection use a flat 16-bit sRGB BigTIFF, a genuine tiled multi-resolution OME-TIFF, and a compact JPEG preview. This is the same general strategy used by aerial imagery and whole-slide systems: retain source tiles, use overviews for navigation, and defer full-resolution rendering.

## Measured Example

| Property | Result |
| --- | ---: |
| Tile positions | 140 |
| Mosaic dimensions | 38,324 x 36,167 |
| Output pixels | 1.386 gigapixels |
| Resolution metadata | 4,998 DPI |
| Working project | 67 GB |
| Operation start to final preview | about 53 minutes |

The output has about 23 times the pixels of a 61 MP Sony A7R V frame and 9.2 times the pixels of a 151 MP Phase One IQ4 frame. That comparison describes spatial output only. MarlinScan scans a static plane over time and is not equivalent to either camera in speed, dynamic range, noise, color, optics, or motion capture.

MarlinScan hardware in motion

The linked clip is an 8-second 720p SDR derivative of the supplied hardware video. The original HDR recordings remain outside the documented application workflow.

## Safety Boundary

Cancel is cooperative: the active atomic hardware or file operation finishes, then no later step starts. The printer stays connected and its verified position remains available. Emergency Stop sends Marlin `M112`, faults the printer session, and requires reconnection and coordinate initialization. Never use remembered-position restore after motors were released, the machine lost power, or the stage moved physically.

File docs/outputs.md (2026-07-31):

# Outputs And Large-Image Workflows

MarlinScan separates archival sources, editable derivatives, delivery images, and navigation previews. No one file serves every purpose.

## Canonical Editable Project

The canonical project is the combination of:

- untouched Nikon `.nef` tiles;
- matching fine JPEGs;
- `captures.json` and `tiles.json` manifests;
- calibration and scan parameters;
- `raw_development.json` with pinned engine versions and global transforms;
- `stitch_meta.json` with exact alignment geometry.

This preserves the greatest future flexibility. Stitching requires demosaicing and geometric warping, so no stitched panorama remains original CFA sensor RAW. ISO is physically set during capture and cannot be changed afterward in NEF, DNG, EXR, or TIFF.

## Per-Tile Files

| File | Role | Editing latitude |
| --- | --- | --- |
| `.nef` | Untouched sensor archive | Highest; original CFA samples and camera metadata |
| `.jpg` | Nikon rendering, analysis, alignment, quick inspection | Lowest; 8-bit camera tone and color baked in |
| `_scene_linear.tif` | Internal float32 linear Rec.2020 working tile | High; demosaiced but values above white and signed gamut retained |
| `.tif` | Deterministic 16-bit sRGB display tile | Moderate; WB, color conversion, gamma, and clipping baked in |

Quick viewers often make a NEF look like the Nikon JPEG because they display the full-size embedded JPEG preview. That is not the sensor data MarlinScan develops.

## Mosaic Files

### `mosaic_scene_linear.exr`

The full-resolution editable derivative is tiled float32 scene-linear Rec.2020 OpenEXR. It retains values above display white and signed wide-gamut values, making it suitable for high-dynamic-range global operations and film inversion. It is demosaiced and stitched, not original sensor RAW.

OpenEXR supports large tiled images and deferred tile access. Use software with genuine tiled OpenEXR support; applications that insist on decoding the whole 1.386 GP frame may require very large memory.

### `mosaic_full.tif`

This is the flat full-resolution 16-bit sRGB BigTIFF. BigTIFF uses 64-bit file offsets so files can exceed 4 GB. It does not by itself provide reduced zoom levels.

Use this artifact for applications that need one conventional full-resolution, display-referred image and can read BigTIFF.

### `mosaic_pyramidal.ome.tif`

This is a real tiled multi-resolution pyramid. The measured output contains a full-resolution 16-bit RGB base, 256 x 256 tiles, eight reduced-resolution SubIFDs, an sRGB ICC profile, resolution metadata, and OME XML.

QuPath should open this exact `.ome.tif` file without generating another pyramid. If QuPath prompts to create one:

1. verify the filename is `mosaic_pyramidal.ome.tif`, not an older `mosaic_pyramidal.tif` or `mosaic_full.tif`;
2. choose the OME-TIFF/OME image server when QuPath offers a reader choice;
3. inspect Image properties and confirm multiple resolutions exist;
4. update QuPath if its current reader does not recognize SubIFD OME pyramids.

A dynamic QuPath pyramid is its own cache and does not prove that MarlinScan's file lacks pyramid levels.

### `mosaic_thumb_2000.jpg`

The JPEG is a maximum-2000-pixel navigation and sharing image. Editor uses it as the instant Full Image proxy. It is never an archival or quantitative master.

## Metadata And Manifests

| File | Contents |
| --- | --- |
| `scan_params.json` | bounds, tile plan, ISO, shutter, focus model, WB, speeds, settle, Quick mode |
| `raw_development.json` | camera matrix, working space, WB, global exposure, engine versions, output transform |
| `captures.json` | incrementally recorded local JPEG/NEF capture pairs |
| `camera_captures.json` | Quick-mode remote camera paths and intended tile mapping |
| `tiles.json` | developed tile roles and coordinates |
| `stitch_meta.json` | source/tile/canvas dimensions, saved transforms, blend, DPI, outputs |

Manifests are fail-fast contracts. An incomplete tile is not written as successful.

## How Very Large Images Are Edited

Gigapixel aerial, map, and whole-slide workflows normally avoid a single giant DNG. They retain source images and transforms, store tiled full-resolution derivatives, build reduced overviews, and render regions on demand.

For MarlinScan:

- navigate and make interactive decisions with the JPEG proxy and one local RAW-derived tile;
- use the EXR or individual scene-linear tiles in software that supports tiled float images;
- apply one versioned recipe tile by tile when a global change must be authoritative;
- reuse alignment instead of stitching again from scratch;
- retain NEFs for a future RAW engine, camera profile, or alternate film model.

## Why DNG Is Not Canonical

The DNG specification can represent demosaiced LinearRaw data and BigTIFF offsets, so a full-resolution BigDNG can be standards-valid. Compatibility is the limiting factor: common Adobe and open-source RAW applications do not reliably edit gigapixel BigDNG mosaics, and Adobe Camera Raw/Lightroom impose image-size limits below the measured 1.386 GP output.

A linear panorama DNG also cannot restore the original Bayer samples after demosaic, warping, and blending. MarlinScan therefore keeps NEFs plus recipes/transforms as the archival source and OpenEXR as the full-resolution editable derivative. A future BigDNG can only be an explicitly experimental export.

## Storage Planning

The measured 140-tile project uses about 67 GB before editor revisions. Each full editor revision can add another EXR, two TIFF mosaics, display tiles, and scratch work during construction. Keep substantially more free space than one final output set; twice the expected project size is a practical minimum, and more is appropriate when preserving revisions.

Quick acquisition reduces USB transfer during stage motion but does not eliminate transfer or processing. Remote files are deleted from the camera after import or cancellation; local completed captures remain for recovery.

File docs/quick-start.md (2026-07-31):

# Quick Start

This walkthrough assumes the camera mount, subject, illumination, manual aperture, and lens focus have already been set physically. Read [Hardware](hardware.md) and [Safety and Recovery](../README.md#safety-and-recovery) before moving the stage.

## 1. Launch

From the repository working directory:

```bash
conda activate 3dprinter
python -m v3se_printer
```

MarlinScan opens `http://127.0.0.1:8000/`. Test captures, calibration, and scans default to `./output/` under this working directory.

## 2. Connect And Initialize Motion

1. Select the printer serial port, baud rate, and line ending.
2. Select **Connect**.
3. Initialize coordinates using exactly one method:
   - **Home** when the complete homing, Z203, and X110/Y110 path is clear.
   - **Set origin** when the current physical location deliberately represents zero.
   - **Restore saved position** only when the machine has not moved physically since MarlinScan last confirmed that position.
4. Confirm that Motion stage reports **Ready** and that X, Y, and Z are credible.

## 3. Connect The Nikon

1. Turn on the Nikon 1 J4 and attach a data-capable Micro-USB cable directly to the Mac.
2. Close Photos, Image Capture, and other camera clients.
3. Select **Take control** to release the macOS camera daemon.
4. Select **Connect**.
5. Choose the global ISO and shutter, then select **Take test photo**.

The latest test JPEG should appear in the central view. The J4 USB driver does not provide video live view; MarlinScan refreshes this view with still captures.

Connected Capture workspace

## 4. Inspect And Position

1. Drag the Exposure ROI over representative subject tones.
2. Drag the Focus ROI over fine, high-contrast detail.
3. Drag the Gray ROI over a neutral gray reference.
4. Inspect the center loupe, luma waveform, midtone meter, P99, and clipping diagnostics.
5. Use the bed map, XYZ fields, or hold-to-jog controls to place the camera.

Automatic preview stills follow Home, position restore, completed absolute moves, and the end of a jog.

## 5. Set Shared Scan Bounds

Calibration and Scan show the same coverage rectangle. Editing any X/Y minimum or maximum updates the matching field in the other tab. **Use current** copies the corresponding live X or Y coordinate into both views.

Defaults are X15-205 mm and Y25-205 mm. These are finished-image edges, not camera-center limits.

## 6. Calibrate

Choose one focus model:

- **Single autofocus** measures the current XYZ point and assumes the entire declared coverage is one constant Z plane.
- **Grid autofocus** measures four quarter-area centers plus the exact center and fits a varying focus surface.

Then run exposure and gray white balance as separate actions, or select **Run all calibration** to run auto exposure, five-point grid autofocus, and gray white balance. A successful calibration reports the selected shutter, exposure diagnostics, focus observations, Z range, and white-balance gains.

## 7. Configure The Scan

1. Confirm the shared bounds.
2. Confirm the measured camera footprint, initially 25 x 17 mm.
3. Select overlap, initially 25 percent.
4. Confirm the estimated X, Y, and nominal DPI.
5. Use the 1000 ms stabilization default unless measurements support a different value.
6. Leave **Quick acquisition** off for immediate local files and live tile updates. Enable it only when the shorter moving phase is worth deferring import and display.
7. Confirm the folder, initially `./output/scans`.

Scan settings and live DPI estimate

## 8. Scan

Select **Start scan**. The top status and position map report the current phase, completed/total units, and ETA. The route is serpentine. Each tile uses the calibrated global exposure, white balance, and focus surface.

Select **Cancel** to stop cooperatively while retaining verified printer connection and position. Use **Emergency stop** only for an immediate motion hazard.

## 9. Review Outputs

Successful work returns to Idle and opens Results. Download links appear only for files that exist. The important outputs are:

- original per-tile NEFs and JPEGs in the scan directory;
- `mosaic_scene_linear.exr` for full-resolution scene-linear editing;
- `mosaic_full.tif` for flat 16-bit delivery;
- `mosaic_pyramidal.ome.tif` for tiled multi-resolution viewing;
- `mosaic_thumb_2000.jpg` for quick review.

Completed scan results

## 10. Edit And Regenerate

Open **Editor**, select the completed scan, and adjust the cached Full Image proxy. Select a rectangle in the RAW tile map to inspect that source tile. Choose Positive/Slide, Color Negative, or B&W Negative, then use Basic, Advanced, and Film controls.

Select **Apply to all RAW** only when the recipe is ready. MarlinScan redevelops every NEF, uses the saved alignment, reports progress and ETA, and writes an immutable numbered revision without changing the originals.

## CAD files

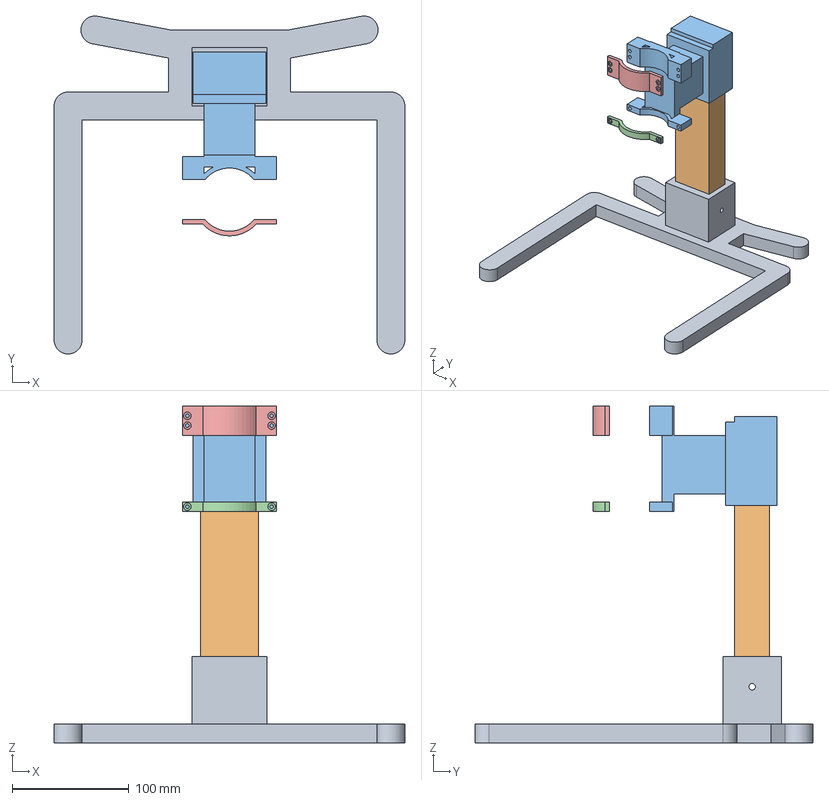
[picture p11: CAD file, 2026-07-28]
3dModel/camera_server/optical_stand.step
300.0 x 289.0 x 288.0 mm
stand_base
rear_mast
lens_carrier
lower_clamp
upper_clamp

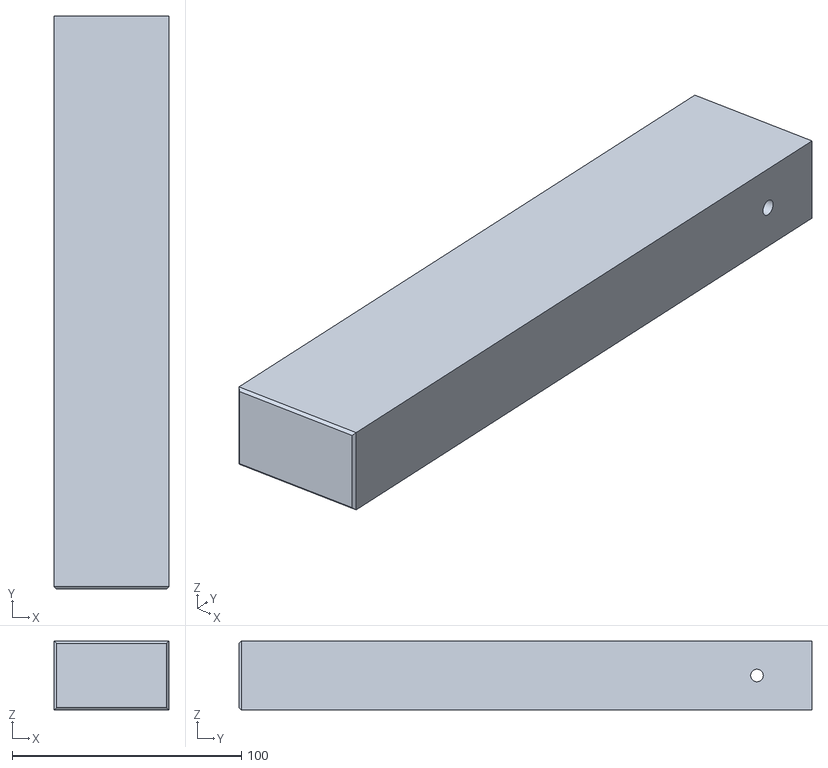
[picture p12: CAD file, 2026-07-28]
3dModel/camera_server/printable/03_rear_mast.stl
50.0 x 250.0 x 30.0

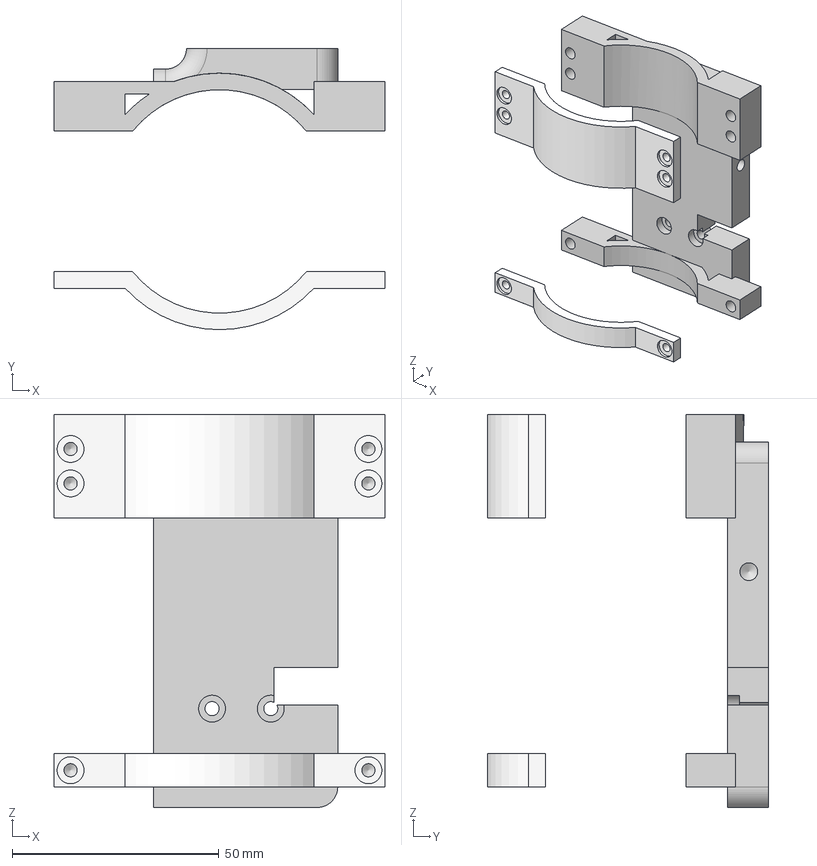
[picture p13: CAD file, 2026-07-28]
3dModel/printer_scan/scanner_mount.step
80.0 x 68.0 x 95.0 mm

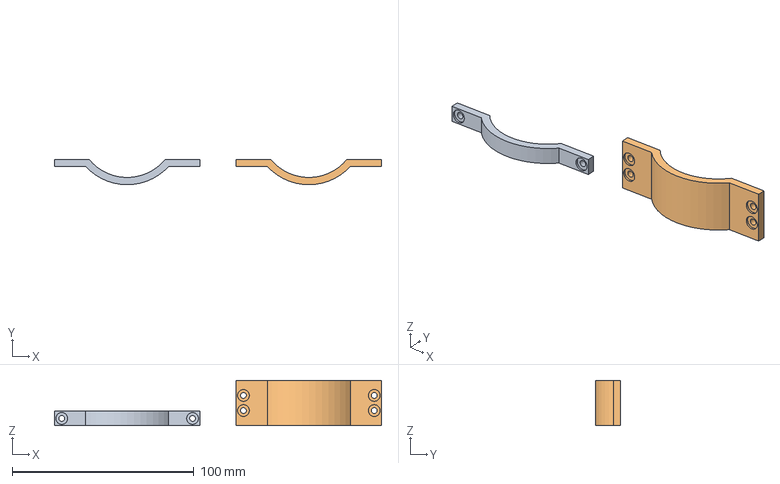
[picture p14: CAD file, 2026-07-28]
3dModel/camera_server/monolithic_clamp_caps.step
180.0 x 14.0 x 25.0 mm
lower_clamp_cap
upper_clamp_cap

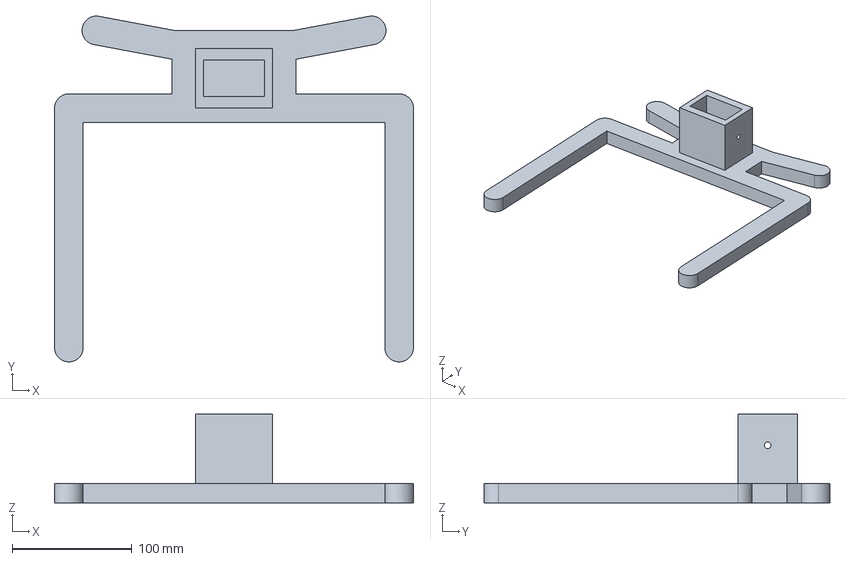
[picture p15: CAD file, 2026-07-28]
3dModel/camera_server/print_stand_base.step
300.0 x 289.0 x 74.0 mm

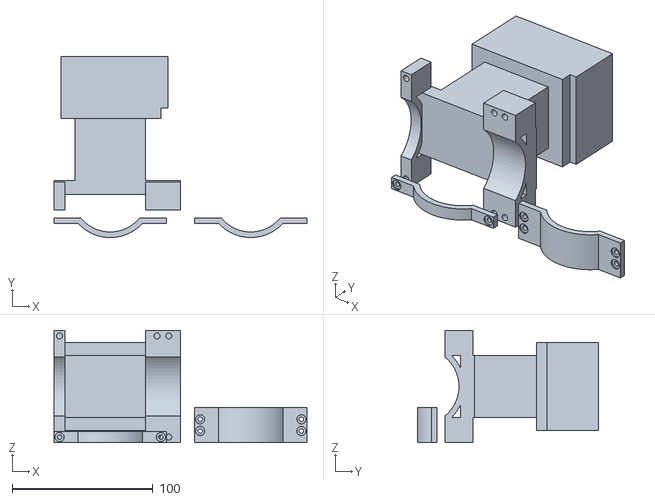
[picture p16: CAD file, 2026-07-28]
3dModel/camera_server/printable/04_optical_head_parts.stl
180.0 x 128.8 x 80.0

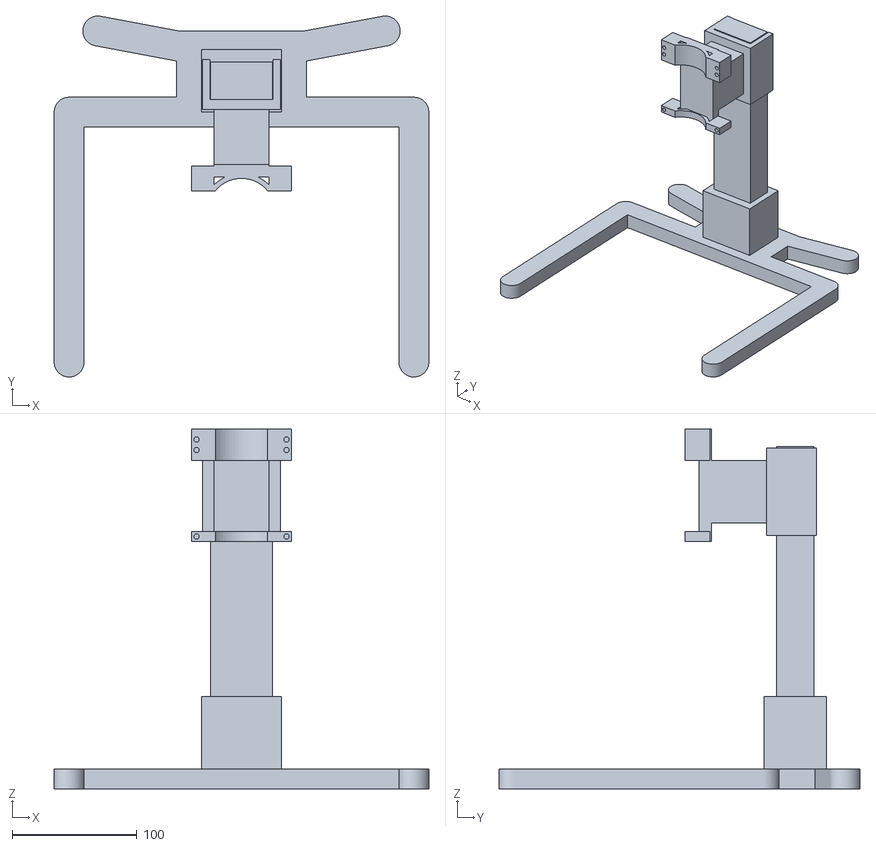
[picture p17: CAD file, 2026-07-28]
3dModel/camera_server/printable/05_monolithic_stand_body.stl
300.0 x 289.0 x 288.0

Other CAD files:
3dModel/camera_server/printable/06_monolithic_clamp_caps.stl
3dModel/camera_server/print_rear_mast.step
3dModel/camera_server/print_optical_head.step
3dModel/camera_server/printable/02_stand_base.stl
3dModel/camera_server/monolithic_stand_body.step
3dModel/printer_scan/scanner_mount.stl

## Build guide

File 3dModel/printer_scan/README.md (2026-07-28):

# Printer-controlled scan mount

These are the original scanner-mount models used by the Marlin printer-controlled scanning workflow in `v3se_printer`.

- `scanner_mount.step`: editable solid model
- `scanner_mount.stl`: print-ready mesh

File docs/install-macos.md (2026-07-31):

# Install On macOS

MarlinScan is developed around the `3dprinter` Conda environment and native Homebrew imaging libraries.

## Native Packages

```bash
brew install gphoto2 vips openexr
```

`gphoto2` supplies libgphoto2 camera support. libvips handles large tiled TIFFs, and OpenEXR supplies the scene-linear master writer dependencies.

Verify:

```bash
gphoto2 --version
vips --version
```

## Conda Environment

Activate the existing environment and install the pinned repository requirements:

```bash
conda activate 3dprinter
python --version
python -m pip install -r requirements.txt
```

The current validated environment uses Python 3.11. Do not install NegPy into this environment: its current project requires Python 3.13, ships a desktop GUI dependency stack, exposes no stable headless API, and its published wheel omits its processing packages.

Verify imports and tests without hardware:

```bash
python -m unittest discover -s tests
```

## Camera Permissions And Ownership

Connect the Nikon directly with a data-capable cable. macOS may start Photos, Image Capture, or `ptpcamerad`. Close photo applications. MarlinScan's **Take control** action terminates the current user's PTP daemon before it initializes the camera.

Do not run a separate `gphoto2` command while MarlinScan is connected; PTP camera interfaces generally have one owner.

## Serial Permission

The browser lists serial ports visible to pyserial. If the printer is missing:

- reconnect its USB cable;
- check System Information for the USB device;
- confirm the expected `/dev/cu.*` entry exists;
- close slicers, terminal consoles, and other serial clients;
- verify the printer's USB serial driver if it requires one.

## Launch

From the repository directory:

```bash
conda activate 3dprinter
python -m v3se_printer
```

Or without activating first:

```bash
conda run -n 3dprinter python -m v3se_printer --no-open
```

The default URL is `http://127.0.0.1:8000/`. It is intentionally local-only.

## Working Directory

Launch from the repository or another deliberate job directory. Browser defaults are relative paths under `./output`, resolved against the service working directory. Starting the service from an unexpected directory changes where these paths point.

## Optional Documentation Browser Test

Playwright is available in the validated Conda environment. Desktop Chrome can exercise the WebGL editor against a completed scan. Hardware-free unit tests remain the default CI boundary; do not automate Home, motion, camera capture, deletion, or a full scan without a person supervising the physical machine.

## Update Procedure

1. Finish or cooperatively cancel active work.
2. Confirm Quick camera cleanup completed.
3. Stop the service.
4. Update code and requirements.
5. Run the complete test suite.
6. Start a fresh service so static files and backend endpoints use the same version.
7. Take a test photo and run a small validation scan before a large job.

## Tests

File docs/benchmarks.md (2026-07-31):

# Measured Benchmark

This benchmark documents one real scan so output-size claims remain reproducible and appropriately qualified.

## Job

| Property | Measured value |
| --- | ---: |
| Date | 2026-07-30 |
| Capture positions | 140, 10 x 14 |
| Finished coverage | 190 x 180 mm |
| Camera footprint | 25 x 17 mm |
| Overlap | 25% |
| ISO / shutter | ISO 160 / 1/13 s |
| Focus | five-point fitted grid surface |
| Acquisition | Quick |
| Recorded settle for this job | 250 ms |
| Output dimensions | 38,324 x 36,167 |
| Output pixels | 1,386,076,508 |
| Resolution metadata | 196.767 px/mm, 4,998 DPI |
| Project size | 67 GB |
| Operation start to final JPEG preview | about 53 minutes |

The product default was increased after this job to 1000 ms stabilization because later inspection found some blur. Do not quote the measured 250 ms as a recommended value.

## Pixel-Count Comparison

| Capture | Nominal output | MarlinScan ratio |
| --- | ---: | ---: |
| Measured MarlinScan mosaic | 1,386 MP | 1.0x |
| Sony A7R V single frame | about 60.2 MP | 23.0x |
| Sony A7R V Pixel Shift | 240.8 MP | 5.75x |
| Phase One IQ4 150MP | about 151 MP | 9.16x |

Sources: [Sony A7R V specifications](https://www.sony.com/electronics/support/e-mount-body-ilce-7-series/ilce-7rm5/specifications), [Sony Pixel Shift](https://electronics.sony.com/imaging/interchangeable-lens-cameras/full-frame/p/ilce7rm5-b), and [Phase One IQ system overview](https://www.phaseone.com/wp-content/uploads/2021/12/IQ_Camera_System_Overview_Flyer.pdf).

These ratios compare output pixel counts only. MarlinScan requires a static, nearly flat subject and many exposures over time. It does not inherit a high-end camera's single-shot dynamic range, noise, color accuracy, lens performance, motion tolerance, or calibrated metrology. Effective resolved detail must be measured from the final image; nominal pixels and DPI are sampling metrics.

## Editor Interaction Benchmark

Desktop Chrome, the real completed project, and the local service produced:

| Interaction | Time | Network behavior |
| --- | ---: | --- |
| Load Full Image proxy | 194-264 ms | one display-proxy JPEG |
| Load first Local RAW tile | 890-895 ms | one RAW-derived tile JPEG |
| Return to cached Full Image | 25-29 ms | no request |
| Slider input through two frames | 25-27 ms | no request |

The former server-side full preview took about 85-89 seconds because it opened, edited, aligned, and blended all 140 float tiles for every click. That path is no longer part of the browser contract.

## Output Validation

The measured `mosaic_pyramidal.ome.tif` has a 38,324 x 36,167 uint16 RGB base, 256 x 256 tiles, eight reduced SubIFDs, ICC profile, resolution metadata, and OME XML. It is a genuine pyramid, not merely BigTIFF addressing.

The scene-linear OpenEXR is float32 tiled Rec.2020. Values above display white are retained before sRGB delivery conversion.

## Reproducing A Benchmark

Record:

1. exact hardware, lens, extension, aperture, light, and subject;
2. scan and RAW-development manifests;
3. operation start and final publication timestamps;
4. output dimensions and DPI metadata;
5. project and scratch disk usage;
6. a resolved-detail target, not only pixel dimensions;
7. any cancellation, warning, retry, or manual intervention.

Do not combine results from different recipes or silently exclude failed time from end-to-end duration.

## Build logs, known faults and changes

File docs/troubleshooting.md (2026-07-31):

# Troubleshooting And Recovery

MarlinScan fails operations visibly instead of guessing around camera, motion, file, or metadata errors. Preserve the first error text; later symptoms can be consequences.

## `[-2] Bad parameters`

This is a libgphoto2 response from a camera property write or capture command. A value can still appear selected in the browser while the attempted profile transition was rejected by the camera. MarlinScan only records a profile or shutter after writing it and reading the same value back; a failed request restores properties already changed and preserves the last fully verified profile.

Use this sequence:

1. Wait until the service state is Idle. Do not change ISO/shutter while a still, autofocus, import, or scan owns the camera.
2. Confirm the Nikon is on, awake, directly connected by a data-capable cable, and not showing a camera-side modal or playback screen.
3. Select **Disconnect** in MarlinScan.
4. Close Photos, Image Capture, tethering tools, and any terminal `gphoto2` process.
5. Select **Take control**, then **Connect**.
6. Choose one shutter from the freshly populated list and wait for the Nikon panel to report the verified value.
7. Take a test photo before calibration or scanning.
8. If Analysis works but RAW fails, check that the camera accepts Large / NEF+Fine in its current state and that its storage target/card is available for Quick mode.
9. If the same property still returns `[-2]`, power-cycle the camera, reconnect the USB cable, and repeat from Take control.

Do not fix this by accepting an unverified readback or silently continuing with another quality. That can pair a displayed shutter with a different physical exposure.

## `Select a global shutter speed before capture`

The service has no verified shutter, even if the select element still displays text from an earlier browser state. Refresh status, reconnect the Nikon, select an advertised finite shutter, and wait for the Camera panel to show it. Bulb and undecodable sentinel choices are not valid automated captures.

## Camera Is Detected But Cannot Connect

macOS `ptpcamerad` commonly owns the PTP interface. Use **Take control** immediately before Connect. This terminates only the current user's exact `/usr/libexec/ptpcamerad` process. Camera ownership can return after disconnect or after another photo application opens.

Also verify:

- exactly one Nikon 1 J4 is detected;
- the cable carries data and is not connected through an unreliable hub;
- no other MarlinScan service or `gphoto2` command owns the camera;
- the camera has not slept or opened a USB/playback prompt.

## Scan Is Underexposed Relative To Nikon JPEG

The Nikon JPEG and embedded NEF preview contain Nikon's picture style and tone curve. MarlinScan develops sensor data deterministically with per-tile auto brightness disabled, then applies one global calibration-derived RAW exposure multiplier. A TIFF is not expected to match an arbitrary Nikon picture style exactly.

Check `raw_development.json` for the global exposure transform and compare the scene-linear tile, display TIFF, and stitched preview. If tile TIFF and mosaic match each other, stitching is not the source of darkening. Recalibrate exposure and gray reference under the scan illumination rather than normalizing individual tiles, which would create seams.

## Exposure Did Not Stay Inside A Fixed P99 Range

There is no hard JPEG P99 233-247 requirement. Auto exposure meters robust middle tones, then optimizes RAW headroom. JPEG P99, clipping, RAW P99, saturation, and black occupancy are diagnostics. A high-contrast scene can require clipped highlights and black shadows. MarlinScan accepts the best available exposure and reports a warning when the camera's discrete shutter range cannot hit the optimization target.

## Blur Or Directional Softness

Increase Scan **Settle (ms)** from the 1000 ms default and repeat a small representative area. Also check:

- camera mount and lens barrel rigidity;
- subject flatness and clamps;
- cable forces on the moving assembly;
- printer acceleration and belt tension;
- whether blur direction matches the preceding X, Y, or Z movement;
- focus ROI texture and the fitted focus-map Z range.

Do not use sharpening to diagnose vibration. Inspect a Local RAW tile at the source resolution.

## Cancel Disconnected The Printer

Normal **Cancel** does not intentionally disconnect. It sets a cooperative stop flag, allows the active atomic command to finish, prevents later commands, returns to Idle, and retains the verified position. **Emergency stop** is different: it sends `M112`, faults the session, and requires reconnecting.

If the printer disappeared after Cancel, inspect the first hardware/serial error and USB connection. A serial transport loss is not converted into an ordinary cancellation.

## Restore Saved Position Is Disabled

Restore is available only after connecting to a port with a remembered confirmed position, while coordinates are not already initialized and the printer is not faulted. Once the current session is initialized, restoring another coordinate state is deliberately disabled.

If a previous emergency stop or serial loss invalidated continuity, Home is the correct recovery even when a saved value exists.

## Quick Acquisition Camera Space

Quick mode records each returned remote JPEG and NEF before import. Success, Cancel, and failure all run job-scoped cleanup and restore the prior capture target. It never enumerates or deletes unrelated card files.

If cleanup fails, the scan fails visibly. Use `camera_captures.json` to identify exact job-owned remote paths. Resolve camera connectivity first, then remove only those listed files with a deliberate camera tool. Never bulk-delete the camera card based on filename patterns.

## Incomplete Or Cancelled Scan Folder

Completed local JPEG/NEF pairs remain on disk. Incremental manifests show exactly what succeeded. A partial scan has no right to claim complete mosaic outputs. Keep it for diagnosis or recoverable restitch work, or remove it manually after confirming it contains nothing needed.

Editor cancellation removes its hidden partial revision directory and does not change the original project or published revisions.

## QuPath Asks To Create A Pyramid

Open `mosaic_pyramidal.ome.tif`, not `mosaic_full.tif` and not an older `mosaic_pyramidal.tif`. The current OME file is already tiled and multi-resolution. See [Outputs](outputs.md#mosaic_pyramidalometif) for reader checks.

## Editor Appears Stuck Or Slow

The current editor should never display `Rendering preview` during a slider change or Full/Local switch. Full Image uses a cached 2000 px mosaic; Local RAW performs one tile request. Browser developer tools should show no `/api/editor/preview` POST.

If the canvas is blank, use current desktop Chrome and confirm WebGL2 plus `EXT_color_buffer_float` are available. The renderer fails visibly rather than falling back to a different image pipeline. If a Local RAW request fails, confirm the service was restarted after upgrading and that `/api/editor/tile-preview` exists.

## Service Restart And Live Hardware

Python backend changes require a service restart. Static files can update while an old service is still running, so a newly loaded browser may expect an endpoint that the old in-memory application does not have. Finish or cancel active work deliberately, then restart the service as one version. Do not reload the service during camera import, cleanup, or output publication.

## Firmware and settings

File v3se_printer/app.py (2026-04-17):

from __future__ import annotations

from collections import deque
import base64
from dataclasses import replace
import os
import queue
import re
import threading
import time
import tkinter as tk
from tkinter import messagebox, scrolledtext, ttk

import serial  # type: ignore

from .models import GCodeJob, PortItem, PrinterConfig, Priority
from .parsers import parse_m105, parse_m114, parse_m115, parse_m503
from .ports import list_serial_ports
from .serial_worker import SerialWorker
from .ui.bed import BedTabMixin
from .ui.maint import MaintTabMixin
from .ui.move import MoveTabMixin
from .ui.quick import QuickTabMixin
from .ui.realtime import RealtimeMixin
from .ui.scan import ScanTabMixin
from .ui.temps import TempsTabMixin
from .ui.tuning import TuningTabMixin
from .uvc import (
    UvcCameraConfig,
    apply_uvc_config,
    compute_sharpness,
    get_capture_info,
    probe_uvc_indices,
    transform_frame,
)


def looks_like_marlin(lines: list[str]) -> bool:
    for line in lines:
        lower = line.lower()
        if "firmware_name" in lower or "marlin" in lower:
            return True
        if "machine_type" in lower and "ender" in lower:
            return True
    return False


def send_and_collect(
    ser: serial.Serial,
    command: str,
    *,
    eol: str,
    timeout_s: float,
) -> list[str]:
    command = command.strip()
    if not command:
        return []

    ending = "\r\n" if eol == "crlf" else "\n"
    ser.write((command + ending).encode("ascii", errors="ignore"))
    ser.flush()

    lines: list[str] = []
    deadline = time.monotonic() + timeout_s
    while time.monotonic() < deadline:
        raw = ser.readline()
        if not raw:
            continue
        text = raw.decode("utf-8", errors="replace").strip()
        if not text:
            continue
        lines.append(text)
        lower = text.lower()
        if lower == "ok" or lower.startswith("ok ") or lower.startswith("error"):
            break
    return lines


class PrinterGUI(
    QuickTabMixin,
    MoveTabMixin,
    BedTabMixin,
    RealtimeMixin,
    ScanTabMixin,
    TempsTabMixin,
    TuningTabMixin,
    MaintTabMixin,
    tk.Tk,
):
    def __init__(self) -> None:
        super().__init__()
        self.title("MarlinScan")
        self.minsize(1050, 640)

        self._ser: serial.Serial | None = None
        self._worker: SerialWorker | None = None
        self._events: queue.Queue[tuple[str, object]] = queue.Queue()

        # Background "wait for command done" helpers (used by camera/printer coordination).
        self._job_waiters_lock = threading.Lock()
        self._job_waiters: dict[str, threading.Event] = {}
        self._job_waiter_results: dict[str, tuple[bool, list[str]]] = {}
        self._job_waiter_seq = 0

        # UVC camera state (optional, requires opencv-python).
        self._cam_lock = threading.Lock()
        self._cam_cap: object | None = None
        self._cam_connected = False
        self._cam_connecting = False
        self._cam_scanning = False
        self._cam_worker_stop = threading.Event()
        self._cam_worker_thread: threading.Thread | None = None
        self._cam_cmd_q: queue.Queue[tuple[str, object]] = queue.Queue()
        self._cam_preview_q: queue.Queue[tuple[float, str, float | None]] = queue.Queue(maxsize=1)  # (ts, b64png, sharp)
        self._cam_preview_last_ts: float | None = None
        self._cam_preview_last_sent_w: int = 960
        self._cam_connected_index: int | None = None
        self._cam_indices: list[int] = []
        self._cam_index_var = tk.StringVar()
        self._cam_status_var = tk.StringVar(value="Camera: Disconnected")
        self._cam_config = UvcCameraConfig()
        self._cam_setup_seen: set[int] = set()
        self._cam_setup_dialog: tk.Toplevel | None = None
        self._cam_af_active = False
        self._cam_af_stop = threading.Event()
        self._cam_preview_active = False
        self._cam_preview_after_id: str | None = None
        self._cam_preview_photo: tk.PhotoImage | None = None
        self._cam_preview_frame_count = 0
        self._cam_preview_consec_fail = 0  # UI-only (worker maintains its own count)
        self._cam_preview_last_fail_note_ts = 0.0  # UI-only
        self._cam_preview_sharp_var = tk.StringVar(value="Sharpness: ?")
        self._cam_preview_info_var = tk.StringVar(value="")
        self._cam_sharp_hist: deque[tuple[float, float]] = deque(maxlen=240)
        self._cam_sharp_plot_last_draw: float = 0.0
        self._cam_frame_cond = threading.Condition()
        self._cam_frame_seq = 0
        self._cam_latest_sharpness: float | None = None
        self._cam_latest_frame_size: tuple[int, int] | None = None  # (w, h) from raw frame
        self._cam_latest_cap_info: str = ""
        self._cam_latest_readback: dict[str, float] = {}
        self._cam_sharp_samples: deque[tuple[float, float]] = deque(maxlen=4000)
        self._cam_latest_frame: object | None = None  # last raw frame (numpy array), best-effort
        self._cam_worker_fail_count: int = 0

        # Bed scan (camera mosaic) state.
        self._scan_active = False
        self._scan_stop = threading.Event()

        self._config = PrinterConfig()
        self._poll_pending_m105 = False
        self._poll_pending_m114 = False
        self._home_prompt_pending = False
        self._home_prompt_seen_m105 = False
        self._home_prompt_seen_m114 = False
        self._home_prompt_shown = False
        self._deferred_m503 = False
        self._startup_home_dialog: tk.Toplevel | None = None
        self._startup_home_pending_jobs = 0
        self._startup_home_motors_enabled: bool | None = None
        self._startup_home_motors_var = tk.StringVar(value="Motors: ?")
        self._startup_home_axis_status: dict[str, str] = {"X": "pending", "Y": "pending", "Z": "pending"}
        self._startup_home_axis_vars: dict[str, tk.StringVar] = {
            "X": tk.StringVar(value="Pending"),
            "Y": tk.StringVar(value="Pending"),
            "Z": tk.StringVar(value="Pending"),
        }
        self._startup_home_status_var = tk.StringVar(value="")
        self._startup_home_continue_btn: ttk.Button | None = None
        self._startup_home_buttons: list[ttk.Button] = []

        self._port_items: list[PortItem] = []
        self._port_var = tk.StringVar()
        self._baud_var = tk.StringVar(value="115200")
        self._eol_var = tk.StringVar(value="crlf")
        self._status_var = tk.StringVar(value="Disconnected")
        self._command_var = tk.StringVar()

        self._firmware_var = tk.StringVar(value="Firmware: ?")
        self._pos_var = tk.StringVar(value="X:?  Y:?  Z:?  E:?")
        self._temp_var = tk.StringVar(value="Hotend:?/?°C  Bed:?/?°C")
        self._auto_poll_var = tk.BooleanVar(value=True)
        self._poll_interval_var = tk.StringVar(value="1.0")
        self._confirm_motion_var = tk.BooleanVar(value=False)
        self._bed_click_move_var = tk.BooleanVar(value=False)

        self._coord_mode_var = tk.StringVar(value="absolute")
        self._step_xy_var = tk.StringVar(value="10")
        self._step_z_var = tk.StringVar(value="1")
        self._max_speed_xy_var = tk.DoubleVar(value=500.0)  # mm/s (UI cap)
        self._max_speed_z_var = tk.DoubleVar(value=15.0)  # mm/s
        self._speed_xy_var = tk.DoubleVar(value=250.0)  # mm/s (default)
        self._speed_z_var = tk.DoubleVar(value=15.0)  # mm/s (default to max)

        self._abs_x_var = tk.StringVar()
        self._abs_y_var = tk.StringVar()
        self._abs_z_var = tk.StringVar()

        self._rel_x_var = tk.StringVar()
        self._rel_y_var = tk.StringVar()
        self._rel_z_var = tk.StringVar()

        self._extrude_amt_var = tk.StringVar(value="5")
        self._extrude_speed_var = tk.StringVar(value="5")  # mm/s

        self._hotend_target_var = tk.StringVar(value="0")
        self._bed_target_var = tk.StringVar(value="0")
        self._fan_var = tk.DoubleVar(value=0.0)  # 0..255

        self._feed_override_var = tk.IntVar(value=100)  # M220 S
        self._flow_override_var = tk.IntVar(value=100)  # M221 S
        self._accel_var = tk.DoubleVar(value=2500.0)  # M204 P/R/T (default)

        # Bed/work-area model (used for absolute positioning UI).
        # Defaults for Ender-3 V3 SE (commonly 220x220x250).
        self._bed_x_min_var = tk.DoubleVar(value=0.0)
        self._bed_x_max_var = tk.DoubleVar(value=220.0)
        self._bed_y_min_var = tk.DoubleVar(value=0.0)
        self._bed_y_max_var = tk.DoubleVar(value=220.0)
        self._bed_z_min_var = tk.DoubleVar(value=0.0)
        self._bed_z_max_var = tk.DoubleVar(value=250.0)

        # Scan tab (camera tile scan) UI state.
        self._scan_status_var = tk.StringVar(value="Scan: Idle")
        self._scan_estimate_var = tk.StringVar(value="Estimate: —")
        self._scan_stitch_progress_var = tk.DoubleVar(value=0.0)
        self._scan_stitch_progress_text_var = tk.StringVar(value="Stitching: idle")
        self._scan_x_min_var = tk.DoubleVar(value=float(self._bed_x_min_var.get()))
        self._scan_x_max_var = tk.DoubleVar(value=float(self._bed_x_max_var.get()))
        self._scan_y_min_var = tk.DoubleVar(value=float(self._bed_y_min_var.get()))
        self._scan_y_max_var = tk.DoubleVar(value=float(self._bed_y_max_var.get()))
        self._scan_step_x_var = tk.StringVar(value="1")
        self._scan_step_y_var = tk.StringVar(value="2")
        self._scan_serpentine_var = tk.BooleanVar(value=True)
        self._scan_focus_plane_var = tk.BooleanVar(value=False)
        self._scan_focus_mesh_var = tk.StringVar(value="3x3")
        self._scan_af_each_tile_var = tk.BooleanVar(value=True)
        self._scan_shots_var = tk.StringVar(value="1")
        self._scan_stack_var = tk.StringVar(value="none")
        self._scan_capture_settle_ms_var = tk.StringVar(value="10")
        self._scan_build_pyramid_var = tk.BooleanVar(value=True)
        self._scan_tiff_compression_var = tk.StringVar(value="lzw")
        self._scan_out_dir_var = tk.StringVar(value=os.path.join(os.getcwd(), "scans"))

        self._target_x_var = tk.DoubleVar(value=0.0)
        self._target_y_var = tk.DoubleVar(value=0.0)
        self._target_z_var = tk.DoubleVar(value=0.0)
        self._z_raw_var = tk.DoubleVar(value=0.0)  # UI slider raw value (inverted to Z target)
        self._current_x: float | None = None
        self._current_y: float | None = None
        self._current_z: float | None = None

        # Realtime bed tracking (mouse → incremental jog streaming).
        self._rt_active = False
        self._rt_mouse_down = False
        self._rt_mouse_inside = False
        self._rt_virtual_x: float | None = None
        self._rt_virtual_y: float | None = None
        self._rt_pending_start = False
        self._rt_pending_acks = 0
        self._rt_restore_coord_mode: str | None = None

        self._rt_hold_mouse_var = tk.BooleanVar(value=True)
        self._rt_tick_hz_var = tk.StringVar(value="100")
        self._rt_step_mm_var = tk.StringVar(value="4")
        self._rt_deadband_mm_var = tk.StringVar(value="0.2")
        self._rt_sync_m400_var = tk.BooleanVar(value=False)
        self._rt_buffer_ms_var = tk.StringVar(value="30")
        self._rt_home_xy_var = tk.BooleanVar(value=False)
        self._rt_boost_motion_var = tk.BooleanVar(value=True)
        self._rt_boost_m201_xy_var = tk.StringVar(value="3000")
        self._rt_boost_m204_var = tk.StringVar(value="3000")
        self._rt_boost_junction_var = tk.StringVar(value="0.20")
        self._rt_boost_applied = False
        self._rt_boost_saved_m201_xy: tuple[float | None, float | None] | None = None
        self._rt_boost_saved_m204: float | None = None
        self._rt_boost_saved_junction: float | None = None

        self._rt_target_x_var = tk.DoubleVar(value=0.0)
        self._rt_target_y_var = tk.DoubleVar(value=0.0)
        self._rt_status_var = tk.StringVar(value="Stopped")
        self._rt_queue_time_s = 0.0
        self._rt_last_tick_time: float | None = None

        # Realtime keyboard jog (arrow keys → XY, Shift/Ctrl → Z).
        self._kb_active = False
        self._kb_pending_start = False
        self._kb_pending_acks = 0
        self._kb_restore_coord_mode: str | None = None
        self._kb_virtual_x: float | None = None
        self._kb_virtual_y: float | None = None
        self._kb_virtual_z: float | None = None
        self._kb_keys_down: set[str] = set()
        self._kb_queue_time_s = 0.0
        self._kb_last_tick_time: float | None = None

        self._kb_tick_hz_var = tk.StringVar(value="100")
        self._kb_step_xy_mm_var = tk.StringVar(value="4")
        self._kb_step_z_mm_var = tk.StringVar(value="0.5")
        self._kb_sync_m400_var = tk.BooleanVar(value=False)
        self._kb_buffer_ms_var = tk.StringVar(value="30")
        self._kb_status_var = tk.StringVar(value="Stopped")
        self._kb_enforce_bounds = True
        self._kb_speed_xy_cap: float | None = None
        self._kb_speed_z_cap: float | None = None

        # Internal binding/paint bookkeeping for realtime modes.
        self._kb_bind_press_id: str | None = None
        self._kb_bind_release_id: str | None = None
        self._kb_bind_widget: tk.Misc | None = None
        self._rt_redraw_after_id: str | None = None
        self._rt_last_redraw_time: float | None = None

        self._build_ui()
        self._set_controls_connected(False)
        self._set_camera_controls_connected(False)
        self.refresh_ports()
        # Startup: do not probe cameras (slow and may trigger permission prompts).
        # Users can type an index manually or click Scan.
        try:
            self.cam_combo["values"] = [str(i) for i in range(6)]
        except Exception:
            pass
        if not self._cam_index_var.get().strip():
            self._cam_index_var.set("0")
        self._cam_status_var.set("Camera: Disconnected (enter index or click Scan)")

        self.after(50, self._drain_events)
        self.after(500, self._poll_tick)
        self.protocol("WM_DELETE_WINDOW", self._on_close)

    def _build_ui(self) -> None:
        cam_top = ttk.Frame(self, padding=10)
        cam_top.pack(side=tk.TOP, fill=tk.X)

        ttk.Label(cam_top, text="Camera:").grid(row=0, column=0, sticky=tk.W)
        self.cam_combo = ttk.Combobox(cam_top, textvariable=self._cam_index_var, width=10, state="normal")
        self.cam_combo.grid(row=0, column=1, sticky=tk.W, padx=(6, 10))

        self.cam_refresh_btn = ttk.Button(cam_top, text="Scan", command=self.refresh_cameras)
        self.cam_refresh_btn.grid(row=0, column=2, sticky=tk.W)

        self.cam_connect_btn = ttk.Button(cam_top, text="Connect", command=self.toggle_camera_connect)
        self.cam_connect_btn.grid(row=0, column=3, sticky=tk.W, padx=(10, 0))

        self.cam_setup_btn = ttk.Button(cam_top, text="Setup", command=self.open_camera_setup)
        self.cam_setup_btn.grid(row=0, column=4, sticky=tk.W, padx=(10, 0))

        self.cam_preview_btn = ttk.Button(cam_top, text="Preview", command=self.toggle_camera_preview)
        self.cam_preview_btn.grid(row=0, column=5, sticky=tk.W, padx=(10, 0))

        self.cam_af_btn = ttk.Button(cam_top, text="Auto Focus (Z)", command=self.toggle_camera_autofocus)
        self.cam_af_btn.grid(row=0, column=6, sticky=tk.W, padx=(10, 0))

        ttk.Label(cam_top, textvariable=self._cam_status_var).grid(
            row=1, column=0, columnspan=7, sticky=tk.W, pady=(8, 0)
        )

        for col in range(7):
            cam_top.grid_columnconfigure(col, weight=0)
        cam_top.grid_columnconfigure(1, weight=1)

        top = ttk.Frame(self, padding=10)
        top.pack(side=tk.TOP, fill=tk.X)

        ttk.Label(top, text="Port:").grid(row=0, column=0, sticky=tk.W)
        self.port_combo = ttk.Combobox(top, textvariable=self._port_var, width=55, state="readonly")
        self.port_combo.grid(row=0, column=1, sticky=tk.W, padx=(6, 10))

        self.refresh_btn = ttk.Button(top, text="Refresh", command=self.refresh_ports)
        self.refresh_btn.grid(row=0, column=2, sticky=tk.W)

        ttk.Label(top, text="Baud:").grid(row=0, column=3, sticky=tk.W, padx=(16, 0))
        self.baud_combo = ttk.Combobox(
            top,
            textvariable=self._baud_var,
            width=10,
            values=["115200", "250000", "230400", "57600", "38400"],
        )
        self.baud_combo.grid(row=0, column=4, sticky=tk.W, padx=(6, 10))

        ttk.Label(top, text="EOL:").grid(row=0, column=5, sticky=tk.W)
        self.eol_combo = ttk.Combobox(
            top,
            textvariable=self._eol_var,
            width=8,
            values=["crlf", "lf"],
            state="readonly",
        )
        self.eol_combo.grid(row=0, column=6, sticky=tk.W, padx=(6, 10))

        self.connect_btn = ttk.Button(top, text="Connect", command=self.toggle_connect)
        self.connect_btn.grid(row=0, column=7, sticky=tk.W)

        self.detect_btn = ttk.Button(top, text="Auto-detect (find port/baud)", command=self.auto_detect)
        self.detect_btn.grid(row=0, column=8, sticky=tk.W, padx=(10, 0))

        ttk.Label(top, textvariable=self._status_var).grid(row=1, column=0, columnspan=9, sticky=tk.W, pady=(8, 0))
        ttk.Label(top, textvariable=self._firmware_var).grid(row=2, column=0, columnspan=9, sticky=tk.W)

        for col in range(9):
            top.grid_columnconfigure(col, weight=0)
        top.grid_columnconfigure(1, weight=1)

        body = ttk.PanedWindow(self, orient=tk.HORIZONTAL)
        body.pack(side=tk.TOP, fill=tk.BOTH, expand=True, padx=10, pady=(0, 10))

        controls = ttk.Frame(body)
        console = ttk.Frame(body)
        body.add(controls, weight=1)
        body.add(console, weight=2)

        status = ttk.LabelFrame(controls, text="Status", padding=10)
        status.pack(side=tk.TOP, fill=tk.X, pady=(0, 10))

        ttk.Label(status, text="Position:").grid(row=0, column=0, sticky=tk.W)
        ttk.Label(status, textvariable=self._pos_var).grid(row=0, column=1, sticky=tk.W, padx=(8, 0))

        ttk.Label(status, text="Temps:").grid(row=1, column=0, sticky=tk.W, pady=(4, 0))
        ttk.Label(status, textvariable=self._temp_var).grid(row=1, column=1, sticky=tk.W, padx=(8, 0), pady=(4, 0))

        ttk.Button(status, text="Query M105", command=lambda: self._send("M105")).grid(
            row=2, column=0, sticky=tk.W, pady=(10, 0)
        )
        ttk.Button(status, text="Query M114", command=lambda: self._send("M114")).grid(
            row=2, column=1, sticky=tk.W, padx=(8, 0), pady=(10, 0)
        )

        ttk.Checkbutton(status, text="Auto refresh", variable=self._auto_poll_var).grid(
            row=3, column=0, sticky=tk.W, pady=(8, 0)
        )
        ttk.Label(status, text="Interval (s):").grid(row=3, column=1, sticky=tk.W, padx=(8, 0), pady=(8, 0))
        ttk.Entry(status, textvariable=self._poll_interval_var, width=6).grid(
            row=3, column=2, sticky=tk.W, padx=(6, 0), pady=(8, 0)
        )

        ttk.Checkbutton(status, text="Confirm moves", variable=self._confirm_motion_var).grid(
            row=4, column=0, sticky=tk.W, pady=(8, 0)
        )

        status.grid_columnconfigure(1, weight=1)

        self.notebook = ttk.Notebook(controls)
        self.notebook.pack(side=tk.TOP, fill=tk.BOTH, expand=True)

        quick_tab = ttk.Frame(self.notebook, padding=10)
        move_tab = ttk.Frame(self.notebook, padding=10)
        bed_tab = ttk.Frame(self.notebook, padding=10)
        bed_realtime_tab = ttk.Frame(self.notebook, padding=10)
        scan_tab = ttk.Frame(self.notebook, padding=10)
        temps_tab = ttk.Frame(self.notebook, padding=10)
        tuning_tab = ttk.Frame(self.notebook, padding=10)
        maint_tab = ttk.Frame(self.notebook, padding=10)

        self.notebook.add(quick_tab, text="Quick")
        self.notebook.add(move_tab, text="Move")
        self.notebook.add(bed_tab, text="Bed")
        self.notebook.add(bed_realtime_tab, text="Bed Realtime")
        self.notebook.add(scan_tab, text="Scan")
        self.notebook.add(temps_tab, text="Temps/Fan")
        self.notebook.add(tuning_tab, text="Tuning")
        self.notebook.add(maint_tab, text="Level/EEPROM")

        self._build_quick_tab(quick_tab)
        self._build_move_tab(move_tab)
        self._build_bed_tab(bed_tab)
        self._build_bed_realtime_tab(bed_realtime_tab)
        self._build_scan_tab(scan_tab)
        self._build_temps_tab(temps_tab)
        self._build_tuning_tab(tuning_tab)
        self._build_maint_tab(maint_tab)

        self.cam_preview_frame = ttk.LabelFrame(console, text="Camera Preview", padding=6)
        self.cam_preview_frame.configure(height=340)
        self.cam_preview_toolbar = ttk.Frame(self.cam_preview_frame)
        self.cam_preview_toolbar.pack(side=tk.TOP, fill=tk.X)
        ttk.Label(self.cam_preview_toolbar, textvariable=self._cam_preview_info_var).pack(side=tk.LEFT)
        ttk.Label(self.cam_preview_toolbar, textvariable=self._cam_preview_sharp_var).pack(side=tk.LEFT, padx=(12, 0))
        self.cam_preview_stop_btn = ttk.Button(self.cam_preview_toolbar, text="Stop Preview", command=self.stop_camera_preview)
        self.cam_preview_stop_btn.pack(side=tk.RIGHT)

        self.cam_sharp_canvas = tk.Canvas(
            self.cam_preview_frame,
            height=60,
            bg="#111111",
            highlightthickness=1,
            highlightbackground="#333333",
        )
        self.cam_sharp_canvas.pack(side=tk.TOP, fill=tk.X, expand=False, pady=(6, 0))

        self.cam_preview_label = tk.Label(
            self.cam_preview_frame,
            text="Preview stopped",
            bg="black",
            fg="white",
        )
        self.cam_preview_label.pack(side=tk.TOP, fill=tk.BOTH, expand=True, pady=(6, 0))

        self.log = scrolledtext.ScrolledText(console, height=20, wrap=tk.WORD, state="disabled")
        self.log.pack(side=tk.TOP, fill=tk.BOTH, expand=True)
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

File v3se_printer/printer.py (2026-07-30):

from __future__ import annotations

from dataclasses import dataclass, field
import math
from pathlib import Path
import queue
import threading
import time
from typing import Callable

import serial  # type: ignore

from .models import GCodeJob, PortItem, Priority
from .parsers import parse_m114, parse_m115
from .ports import list_serial_ports
from .position_store import PrinterPositionStore
from .serial_worker import SerialWorker, default_timeout_for_command


class PrinterError(RuntimeError):
    pass


class PrinterStateError(PrinterError):
    pass


class PrinterCommandError(PrinterError):
    pass


class PrinterTimeoutError(PrinterError):
    pass


class PrinterStoppedError(PrinterError):
    pass


@dataclass(frozen=True)
class MotionBounds:
    x_min: float = 0.0
    x_max: float = 220.0
    y_min: float = 0.0
    y_max: float = 220.0
    z_min: float = 0.0
    z_max: float = 250.0

    def __post_init__(self) -> None:
        values = (self.x_min, self.x_max, self.y_min, self.y_max, self.z_min, self.z_max)
        if not all(math.isfinite(value) for value in values):
            raise ValueError("Motion bounds must be finite")
        if self.x_min >= self.x_max or self.y_min >= self.y_max or self.z_min >= self.z_max:
            raise ValueError("Motion bounds must have increasing minimums and maximums")

    def require(self, x: float, y: float, z: float) -> None:
        if not self.x_min <= x <= self.x_max:
            raise ValueError(f"X must be between {self.x_min:g} and {self.x_max:g} mm")
        if not self.y_min <= y <= self.y_max:
            raise ValueError(f"Y must be between {self.y_min:g} and {self.y_max:g} mm")
        if not self.z_min <= z <= self.z_max:
            raise ValueError(f"Z must be between {self.z_min:g} and {self.z_max:g} mm")


@dataclass(frozen=True)
class Position:
    x: float
    y: float
    z: float
    e: float | None = None


@dataclass(frozen=True)
class PrinterStatus:
    connected: bool
    initialized: bool
    faulted: bool
    port: str | None
    baud: int | None
    position: Position | None
    firmware: str | None
    machine: str | None
    error: str | None
    remembered_position: Position | None = None


@dataclass
class _CommandWaiter:
    event: threading.Event = field(default_factory=threading.Event)
    result: tuple[bool, list[str]] | None = None
    error: PrinterError | None = None


class PrinterController:
    _EXECUTE_COMMANDS = frozenset({"M105", "M114", "M115", "M119", "M400", "M503"})
    _DEFAULT_POSITION_STORE = Path.home() / ".marlinscan" / "printer_positions.json"

    def __init__(
        self,
        bounds: MotionBounds = MotionBounds(),
        *,
        serial_factory: Callable[..., object] = serial.Serial,
        worker_factory: Callable[..., SerialWorker] = SerialWorker,
        port_lister: Callable[..., list[PortItem]] = list_serial_ports,
        connect_delay_s: float = 2.0,
        position_store_path: str | Path = _DEFAULT_POSITION_STORE,
    ) -> None:
        if not math.isfinite(connect_delay_s) or connect_delay_s < 0:
            raise ValueError("connect_delay_s must be finite and non-negative")
        self.bounds = bounds
        self._serial_factory = serial_factory
        self._worker_factory = worker_factory
        self._port_lister = port_lister
        self._connect_delay_s = connect_delay_s
        self._position_store = PrinterPositionStore(position_store_path)
        self._state_lock = threading.RLock()
        self._command_lock = threading.RLock()
        self._lifecycle_lock = threading.Lock()
        self._serial: object | None = None
        self._worker: SerialWorker | None = None
        self._dispatcher: threading.Thread | None = None
        self._dispatcher_stop: threading.Event | None = None
        self._waiters: dict[str, _CommandWaiter] = {}
        self._tag_sequence = 0
        self._connected = False
        self._initialized = False
        self._faulted = False
        self._port: str | None = None
        self._baud: int | None = None
        self._position: Position | None = None
        self._firmware: str | None = None
        self._machine: str | None = None
        self._error: str | None = None
        self._remembered_position: Position | None = None

    def list_ports(self, *, include_dialin: bool = True) -> list[PortItem]:
        return self._port_lister(include_dialin=include_dialin)

    def status(self) -> PrinterStatus:
        with self._state_lock:
            return PrinterStatus(
                connected=self._connected,
                initialized=self._initialized,
                faulted=self._faulted,
                port=self._port,
                baud=self._baud,
                position=self._position,
                firmware=self._firmware,
                machine=self._machine,
                error=self._error,
                remembered_position=self._remembered_position,
            )

    def connect(self, port: str, *, baud: int = 115200, eol: str = "crlf") -> PrinterStatus:
        port = port.strip()
        if not port:
            raise ValueError("Serial port is required")
        if isinstance(baud, bool) or not isinstance(baud, int) or baud <= 0:
            raise ValueError("Baud rate must be a positive integer")
        if eol not in {"crlf", "lf"}:
            raise ValueError("EOL must be 'crlf' or 'lf'")
        remembered = self._position_store.get(port)
        if remembered is not None:
            self.bounds.require(*remembered)

        with self._lifecycle_lock, self._command_lock:
            with self._state_lock:
                if self._connected or self._worker is not None:
                    raise PrinterStateError("Printer is already connected")
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

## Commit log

2026-02-01 add Bed Realtime feature for mouse tracking and update README
2026-02-01 Enhance Bed Realtime feature with new motion boost options and buffer settings; update README and add rt_bench.py for benchmarking
2026-02-01 Refactor bed realtime handling to initialize target positions and improve status updates; enhance M114 response processing
2026-02-02 Add temperature control and tuning tabs to the UI
    - Implemented the TempsTabMixin for managing hotend and bed temperatures, including setting, applying, and cooling down functionalities.
    - Added fan control features with adjustable speed and on/off options.
    - Created the TuningTabMixin for speed and flow overrides, as well as acceleration settings.
    - Integrated user input validation and error handling for temperature and speed settings.
    - Enhanced UI layout with appropriate labels, buttons, and input fields for better user interaction.
    [app.py, maint.py]
2026-02-03 Enhance keyboard controls for manual positioning; update UI and bindings for improved responsiveness
    [app.py, maint.py]
2026-02-19 Add camera control
2026-02-21 Add 2 stage for small and large scan
2026-02-22 better stiching corrected for small misalignment
    [restitch_scan.py]
2026-02-22 fix high res blend
    [restitch_scan.py]
2026-04-17 add mount model file. Improve readme
    [scaner_mount.stl]
2026-07-28 feat: add standalone camera server and split hardware models
    - package the camera server with its dedicated CAD models
    - separate the original printer-controlled scanner mount
    - remove the unused model 01 assets
    - update tests, launch commands, and documentation
    [02_stand_base.stl, 03_rear_mast.stl, 04_optical_head_parts.stl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]
2026-07-28 reorg 3d files
    [02_stand_base.stl, 03_rear_mast.stl, 04_optical_head_parts.stl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]
2026-07-30 feat: add browser-based Nikon RAW scanning workflow
    - add safe Marlin motion, calibration, scan planning,
    cancellation, and ETA tracking
    - add persistent Nikon J4 control with RAW exposure, autofocus,
    and white-balance calibration
    - support normal and camera-card quick acquisition with job-owned
    file cleanup
    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
